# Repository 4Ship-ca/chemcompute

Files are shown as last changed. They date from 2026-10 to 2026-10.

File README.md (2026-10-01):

# chemcompute: WetStack-0

A home-lab chemical neuron: electrons in, chemistry decides, light out.

Charge pulses at platinum electrodes write acid or base into micro-chambers. A borax buffer sets each
chamber's firing threshold, a pH indicator shows its state, a camera and optical fiber read it, and reverse
charge resets it with no fluid replaced. The MVP ends with a two-layer chemical network computing XOR,
an ionic hydrogel diode, fiber readout and solar power, each proven by a pass/fail gate.

**Lab workspace (progress, gates, parts, photos, ask the lab manager):**
https://claude.ai/artifact/Spr4Hz1cUCdgWMjxmdhvYG

## Quick start

**Windows, one click:** double-click `start_wetstack.bat` in the repo folder. It finds Python 3.10+
(3.12 preferred), creates `.venv`, checks every dependency and installs or repairs what's missing,
runs the self-test after a fresh install, then starts the lab workspace and opens it in your browser.
Double-click it again while it's running and it just reopens the page. From a prompt it also runs any
other command in the venv: `start_wetstack.bat gate G0`, `start_wetstack.bat g1-linearity --sim`.
It serves on port 8765, or the next free port if another program already has it; set
`WETSTACK_PORT` to start the search somewhere else.

By hand (Windows or Linux):

```
python -m venv .venv
.venv\Scripts\activate          # Linux: source .venv/bin/activate
pip install -e .
python -m wetstack selftest     # every gate against the digital twin, about 30 s, must end PASSED
```

Then start every bench session with:

```
python -m wetstack serve --open
```

That opens the lab workspace in your browser and saves everything into the repo:
`progress/progress.json` (the master record), `PROGRESS.md` (checkboxes for GitHub) and
`photos/<step>/`. Saves are atomic, every save keeps a backup in `progress/backups/`, and if the
server stops, edits wait in the browser and save when it returns. The workspace's
Save and sync tab has a Commit button that commits and pushes the session.

Every experiment command takes `--sim` so you can rehearse it before using liquids:

```
python -m wetstack g1-linearity --sim
python -m wetstack gate G1 --sim
```

## Layout

| Path | What it is |
|---|---|
| `docs/LAB_MANUAL.md` | The full plan: path, architecture, materials, methods, every phase, step and gate |
| `bom/` | Parts lists with CAD estimates and AliExpress / Amazon search terms |
| `host/wetstack/` | Python package: experiments, camera pipeline, statistics, serial link, digital twin |
| `firmware/wetstack_ctl/` | ESP32 controller firmware (Arduino IDE) |
| `hardware/scad/`, `hardware/stl/` | Parametric OpenSCAD parts and ready STLs (plate frame, lid, fiber couplers) |
| `proofs/` | Gate proof files written by the experiment commands |
| `data/raw/` | Raw session data, never edited |
| `config/lab.json` | Your bench settings (created on first run) |
| `progress/progress.json` | Master progress record written by `python -m wetstack serve`; never edit by hand |
| `photos/<step>/` | Bench photos, resized to 1600 px |
| `tests/` | `test_progress.py` (storage) and `test_cli.py` (every manual command parses) must pass; `e2e_workspace.py` is the browser test (needs Playwright) |
| `tools/content.py` | Single source for the manual, BOM and workspace; rebuild with `python tools/build.py` |
| `start_wetstack.bat`, `tools/check_env.py` | Windows one-click launcher and the dependency / running-server check it uses |
| `web/` | Workspace page (offline copy works in any browser, saving to that browser only) |

## Status at handover

- Digital twin self-test: all ten gates pass.
- CAD: all parts render as manifold solids in OpenSCAD. Measure your plate and edit the parameters before printing the lid.
- Firmware: passes a syntax and type check against stub headers. It has not yet been compiled for a real ESP32; that is step P3.2.
- Real-bench results: none yet. That's your job.

## After each session

1. In the workspace, Sync tab: save `PROGRESS.md` and the progress JSON into the repo root.
2. `git add -A && git commit -m "session YYYYMMDD-x"`; tag passed gates (`git tag G1-pass`).
3. `git push --follow-tags`

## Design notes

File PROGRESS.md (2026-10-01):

# WetStack-0 progress

Starter file. Replace it with the PROGRESS.md exported from the workspace Sync tab after each session.

## P0 Bench, safety and calibration

- [ ] P0.1 Inventory against the BOM
- [ ] P0.2 Set up the bench
- [ ] P0.3 Install the software
- [ ] P0.4 Check the scale
- [ ] P0.5 Calibrate the 1000 uL pipette
- [ ] P0.6 Calibrate the 100 uL pipette
- [ ] P0.7 Read the safety rules and sign off

Gate G0 Bench certified: open

## P1 Eyes: the optical readout bench

- [ ] P1.1 Print the plate frame
- [ ] P1.2 Build the light station
- [ ] P1.3 Lock the camera
- [ ] P1.4 Mark the wells
- [ ] P1.5 Make the bromothymol blue stock (0.4 mg/mL)
- [ ] P1.6 Make 0.1 M sodium carbonate
- [ ] P1.7 Run the dilution series
- [ ] P1.8 Stability run

Gate G1 First light: open

## P2 First nonlinearity: manual XOR

- [ ] P2.1 Make the phenol red stock (0.2 mg/mL)
- [ ] P2.2 Make the input stocks
- [ ] P2.3 Balance the inputs
- [ ] P2.4 Make the XOR medium
- [ ] P2.5 Run the dual-indicator plates
- [ ] P2.6 Run the single-indicator control plate

Gate G2 First XOR: open

## P3 Electric write: the Faraday cell

- [ ] P3.1 Build the controller
- [ ] P3.2 Flash the firmware
- [ ] P3.3 Dry test the relays
- [ ] P3.4 Print and fit the lid
- [ ] P3.5 Make the electrodes
- [ ] P3.6 Verify the platinum
- [ ] P3.7 Make salt bridges
- [ ] P3.8 Calibrate coulomb counting
- [ ] P3.9 Standards and dose response

Gate G3 First electric write: open

## P4 The chemical neuron: threshold and reset

- [ ] P4.1 Make neuron media
- [ ] P4.2 Threshold sweep
- [ ] P4.3 Overnight reset run

Gate G4 First chemical neuron: open

## P5 Logic and the first stack

- [ ] P5.1 Find the AND and OR buffer levels
- [ ] P5.2 Truth tables
- [ ] P5.3 Wire the stack
- [ ] P5.4 Run 40 randomized trials
- [ ] P5.5 Cut-link control

Gate G5 First stack: open

## P6 Junctions: the ionic diode

- [ ] P6.1 Make Ag/AgCl electrodes
- [ ] P6.2 Cationic gel
- [ ] P6.3 Anionic gel
- [ ] P6.4 Cast three diode tubes and one control
- [ ] P6.5 I-V sweeps
- [ ] P6.6 Hysteresis on the scope

Gate G6 First diode: open

## P7 Fiber eyes

- [ ] P7.1 Print fiber parts
- [ ] P7.2 Cut and polish fiber
- [ ] P7.3 Assemble and read
- [ ] P7.4 Dose sweep with both readers

Gate G7 Fiber eyes: open

## P8 Sun power and energy per operation

- [ ] P8.1 Build the power board
- [ ] P8.2 Daylight session

Gate G8 Sun-powered: open

## P9 MVP integration

- [ ] P9.1 Full demo run
- [ ] P9.2 Generate the report
- [ ] P9.3 Debrief

Gate G9 MVP complete: open

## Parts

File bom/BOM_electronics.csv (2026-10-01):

id | name | qty | unit_cad_low | unit_cad_high | line_cad_low | line_cad_high | source | search_terms | first_needed | on_hand | notes
E01 | ESP32 DevKit V1 (classic ESP32-WROOM-32, 38-pin) | 2 | 6 | 12 | 12 | 24 | AliExpress | ESP32 DevKit V1 WROOM-32 38pin | P3 | no | Must be classic ESP32: S2, S3 and C3 have no DAC. Second board is a spare.
E02 | ADS1115 16-bit ADC module | 3 | 3 | 6 | 9 | 18 | AliExpress | ADS1115 module 16 bit | P3 | no | One shunt, one diode I-V, one spare. Set the second to address 0x49 (ADDR to VDD).
E03 | AS7341 11-channel spectral sensor module | 2 | 14 | 38 | 28 | 76 | AliExpress / Amazon (Adafruit) | AS7341 spectral sensor module | P7 | no | Adafruit version is easiest; Ali clones work with the same library.
E04 | 8-channel 5 V relay module, optocoupled, with JD-VCC jumper | 1 | 7 | 14 | 7 | 14 | AliExpress | 8 channel relay module 5V optocoupler | P3 | no | Low-level trigger type.
E05 | INA219 current/power module | 2 | 2 | 6 | 4 | 12 | AliExpress | INA219 module | P8 | no
E06 | DS18B20 waterproof temperature probe | 2 | 2 | 5 | 4 | 10 | AliExpress | DS18B20 waterproof probe | P3 | no
E07 | Logic-level MOSFET switch module (AO3400 or D4184) | 3 | 1 | 3 | 3 | 9 | AliExpress | D4184 MOSFET module | P3 | no | Not IRF520 modules: they do not switch fully at 3.3 V.
E08 | Coin vibration motors 10 mm, 3 V (10-pack) | 1 | 3 | 7 | 3 | 7 | AliExpress | coin vibration motor 1027 3V | P3 | no | Mixer.
E09 | MT3608 boost converter | 3 | 1 | 3 | 3 | 9 | AliExpress | MT3608 boost module | P8 | no
E10 | 9 V 1 A DC adapter + barrel jack breakout | 1 | 10 | 18 | 10 | 18 | Amazon | 9V 1A power adapter 5.5x2.1 | P3 | no
E11 | Inline fuse holder + 250 mA fast fuses | 1 | 5 | 10 | 5 | 10 | Amazon | inline fuse holder 5x20 250mA | P3 | no | Required.
E12 | 1% resistor kit (incl. 100, 470, 1k, 4.7k ohm) | 1 | 8 | 14 | 8 | 14 | AliExpress | 1% metal film resistor kit | P3 | yes | Verify on hand.
E13 | Perfboard, screw terminals, headers | 1 | 8 | 15 | 8 | 15 | AliExpress | perfboard screw terminal kit | P3 | no
E14 | Breadboard and jumper wires | 1 | 8 | 12 | 8 | 12 | AliExpress | 830 breadboard jumper kit | P3 | yes | Verify on hand.
E17 | TCA9548A I2C multiplexer | 1 | 2 | 4 | 2 | 4 | AliExpress | TCA9548A module | Stretch | no | For several AS7341 later.
O05 | 5 mm LED assortment (white, 450, 590, 630 nm) | 1 | 5 | 10 | 5 | 10 | AliExpress | 5mm LED assortment kit | P7 | no
O06 | 365 nm UV LEDs, 5 mm (20-pack) | 1 | 4 | 9 | 4 | 9 | AliExpress | 365nm UV LED 5mm | Stretch | no
S01 | Solar panel 6 V, 6 W | 1 | 18 | 35 | 18 | 35 | Amazon / AliExpress | 6V 6W solar panel | P8 | no
S02 | CN3791 MPPT single-cell solar charger module | 1 | 3 | 7 | 3 | 7 | AliExpress | CN3791 solar charger 6V | P8 | no | Get the 6 V input version.
S04 | 18650 holder with leads | 2 | 1 | 3 | 2 | 6 | AliExpress | 18650 battery holder | P8 | no

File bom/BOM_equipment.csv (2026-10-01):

id | name | qty | unit_cad_low | unit_cad_high | line_cad_low | line_cad_high | source | search_terms | first_needed | on_hand | notes
E15 | Multimeter with uA/mA ranges | 1 | 25 | 50 | 25 | 50 | Amazon | auto ranging multimeter microamp | P3 | yes | Verify on hand.
E16 | Oscilloscope | 1 | 0 | 0 | 0 | 0 | On hand |  | P6 | yes | On hand.
O01 | LED tracing light pad, A4, dimmable | 1 | 22 | 38 | 22 | 38 | Amazon | A4 LED light pad tracing dimmable | P1 | no | Even backlight for the plate.
O02 | USB webcam with manual exposure (Logitech C920/C922 class) | 1 | 50 | 110 | 50 | 110 | Amazon | Logitech C920 | P1 | no | Manual exposure and white balance are the requirement.
O03 | Overhead camera arm / desk mount | 1 | 20 | 38 | 20 | 38 | Amazon | overhead camera desk mount arm 1/4 | P1 | no
O07 | UV-blocking safety glasses | 1 | 10 | 22 | 10 | 22 | Amazon | UV protection safety glasses 365nm | Stretch | no
O08 | 18% gray / white reference card | 1 | 8 | 15 | 8 | 15 | Amazon | 18% gray card | P1 | yes | Verify on hand.
L01 | Adjustable micropipette 100-1000 uL | 1 | 25 | 60 | 25 | 60 | AliExpress / Amazon | adjustable micropipette 100-1000ul | P0 | no
L02 | Adjustable micropipette 10-100 uL | 1 | 25 | 60 | 25 | 60 | AliExpress / Amazon | adjustable micropipette 10-100ul | P0 | no
L05 | Digital scale 0.001 g / 50 g with calibration weight | 1 | 25 | 48 | 25 | 48 | Amazon | 0.001g digital scale 50g | P0 | no
L06 | Borosilicate beaker set 50-500 mL | 1 | 18 | 32 | 18 | 32 | Amazon | borosilicate beaker set | P0 | no
L07 | Graduated cylinders 10/50/100 mL | 1 | 14 | 26 | 14 | 26 | Amazon | graduated cylinder set | P0 | no
L13 | pH meter pen (0.01, ATC) + calibration powders | 1 | 20 | 42 | 20 | 42 | Amazon | pH meter 0.01 ATC calibration | P0 | no
L14 | Digital caliper 150 mm | 1 | 12 | 25 | 12 | 25 | AliExpress | digital caliper 150mm | P0 | no
L15 | Small magnetic hotplate stirrer + stir bars | 1 | 60 | 120 | 60 | 120 | Amazon | magnetic stirrer hot plate | P1 | no | Recommended. Microwave in short bursts is the fallback.
L16 | Silicone bench mat / spill tray | 1 | 10 | 22 | 10 | 22 | Amazon | silicone work mat large | P0 | no
L18 | Safety glasses (Z87.1) | 2 | 6 | 15 | 12 | 30 | Amazon | safety glasses Z87 | P0 | no
L23 | Fireproof LiPo charging bag | 1 | 10 | 18 | 10 | 18 | Amazon | lipo safe bag | P8 | no
L26 | 3D printers (resin + filament) | 1 | 0 | 0 | 0 | 0 | On hand |  | P1 | yes | On hand.

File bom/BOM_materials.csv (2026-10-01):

id | name | qty | unit_cad_low | unit_cad_high | line_cad_low | line_cad_high | source | search_terms | first_needed | on_hand | notes
O04 | PMMA end-glow optical fiber, 1.0 mm, 10 m | 1 | 8 | 16 | 8 | 16 | AliExpress | PMMA optical fiber 1mm end glow | P7 | no
O09 | Black foam board (2 sheets) for the light shroud | 1 | 6 | 14 | 6 | 14 | Local / Amazon | black foam board | P1 | no
L03 | Pipette tips 1000 uL (500) + 200 uL (1000) | 1 | 10 | 22 | 10 | 22 | AliExpress | pipette tips 1000ul 200ul | P0 | no
L04 | 24-well flat-bottom clear plates with lids (10-pack) | 1 | 18 | 38 | 18 | 38 | Amazon / AliExpress | 24 well plate flat bottom | P1 | no | Polystyrene, clear, flat bottom.
L08 | Amber glass dropper bottles 30 mL (12) | 1 | 12 | 20 | 12 | 20 | Amazon | amber glass dropper bottles 30ml | P1 | no
L09 | Storage bottles 250/500 mL (6) | 1 | 15 | 30 | 15 | 30 | Amazon | glass media bottle 500ml | P0 | no
L10 | Wash bottles 250/500 mL | 2 | 3 | 6 | 6 | 12 | AliExpress | lab wash bottle 500ml | P0 | no
L11 | Silicone tubing 2 mm ID x 3 mm OD, 5 m | 1 | 6 | 12 | 6 | 12 | AliExpress | silicone tube 2mm ID 3mm OD | P3 | no | Salt bridges and diode tubes.
L12 | 10 mL luer syringes (10) + blunt needles 14-18 G | 1 | 10 | 18 | 10 | 18 | Amazon | 10ml syringe blunt tip needle | P3 | no
L17 | Nitrile gloves (100) | 1 | 10 | 18 | 10 | 18 | Amazon / local | nitrile gloves | P0 | no
L19 | Lab notebook, labels, waterproof markers | 1 | 10 | 20 | 10 | 20 | Local |  | P0 | no
L20 | Transfer pipettes 3 mL (100) | 1 | 5 | 10 | 5 | 10 | AliExpress | plastic transfer pipette 3ml | P0 | no
L22 | Weighing boats, spatulas, small funnels | 1 | 8 | 16 | 8 | 16 | AliExpress | lab spatula weighing boat set | P0 | no
L27 | PETG filament / clear resin | 1 | 0 | 0 | 0 | 0 | On hand |  | P1 | yes | On hand. PETG for wet parts.
X01 | Platinum wire 0.3 mm x 10 cm, 99.95% | 1 | 15 | 45 | 15 | 45 | AliExpress | platinum wire 0.3mm 99.95 | P3 | no | Verify with step P3.6.
X02 | Graphite rods 2 mm (pure, art leads) | 1 | 6 | 12 | 6 | 12 | Amazon / AliExpress | 2mm graphite lead refill pure | P3 | no | Counter electrode; Pt fallback.
X03 | Silver wire 999, 0.5 mm x 1 m | 1 | 15 | 40 | 15 | 40 | AliExpress | 999 silver wire 0.5mm | P6 | no | For Ag/AgCl.
C01 | Distilled water, 4 L | 4 | 2 | 4 | 8 | 16 | Grocery |  | P0 | no
C02 | Bromothymol blue powder (5-10 g) | 1 | 12 | 28 | 12 | 28 | Amazon | bromothymol blue powder | P1 | no | Backup: aquarium pH test solution (bromothymol blue).
C03 | Phenol red powder (5 g) or 0.02% solution | 1 | 12 | 28 | 12 | 28 | Amazon | phenol red indicator | P2 | no | Pool test phenol red works if concentration is listed.
C04 | Universal indicator solution 100 mL | 1 | 12 | 20 | 12 | 20 | Amazon | universal indicator solution | P2 | no | Backup for XOR.
C05 | Sodium sulfate anhydrous 500 g | 1 | 12 | 22 | 12 | 22 | Amazon | sodium sulfate anhydrous | P1 | no
C06 | Sodium bisulfate (pool pH Down, 93%+) 1 kg | 1 | 10 | 16 | 10 | 16 | Amazon / pool store | sodium bisulfate pH down | P2 | no
C07 | Sodium carbonate (washing soda / pH Up) 1 kg | 1 | 6 | 12 | 6 | 12 | Grocery / Amazon | washing soda sodium carbonate | P1 | no
C09 | Disodium phosphate, food grade, 250-500 g | 1 | 12 | 22 | 12 | 22 | Amazon | disodium phosphate food grade | P2 | no | Note the hydrate form on the label.
C22 | Borax (sodium tetraborate decahydrate), laundry grade OK | 1 | 6 | 14 | 6 | 14 | Grocery / Amazon | 20 Mule Team Borax | P4 | no | Neuron buffer. Gloves; keep from kids and pets.
C10 | Monosodium phosphate, food grade, 250-500 g | 1 | 12 | 22 | 12 | 22 | Amazon | monosodium phosphate food grade | P2 | no
C11 | Agar-agar powder 100 g | 1 | 10 | 16 | 10 | 16 | Grocery / Amazon | agar agar powder | P3 | no | Salt bridges.
C12 | Agarose LE, molecular biology grade, 25 g | 1 | 35 | 70 | 35 | 70 | Amazon | agarose powder molecular biology | P6 | no | Low charge; agar is not a substitute for the diode.
C13 | Chitosan powder, medium MW, 100 g | 1 | 20 | 38 | 20 | 38 | Amazon | chitosan powder | P6 | no | Cationic side of the diode.
C14 | Sodium alginate, food grade, 100 g | 1 | 10 | 18 | 10 | 18 | Amazon | sodium alginate | P6 | no | Anionic side.
C15 | Sodium polyacrylate (SAP) 250 g | 1 | 10 | 16 | 10 | 16 | Amazon | sodium polyacrylate powder | P6 | no | Backup anionic side.
C21 | Non-iodized table salt | 1 | 2 | 4 | 2 | 4 | Grocery |  | P6 | no | Diode test wells only.
C16 | White vinegar 5% | 1 | 3 | 5 | 3 | 5 | Grocery |  | P6 | no
C17 | Isopropyl alcohol 99%, 500 mL | 1 | 8 | 15 | 8 | 15 | Pharmacy / Amazon | isopropyl alcohol 99% | P1 | no
C18 | Household bleach, unscented | 1 | 3 | 6 | 3 | 6 | Grocery |  | P6 | no | Own labeled jar. Never near acids.
C19 | Calcium chloride food grade 250 g | 1 | 8 | 14 | 8 | 14 | Amazon | calcium chloride food grade | Stretch | no
C20 | Photochromic pigment powder 10 g | 1 | 6 | 12 | 6 | 12 | AliExpress | photochromic pigment powder UV | Stretch | no
S03 | Protected 18650 Li-ion cell, reputable brand | 2 | 12 | 25 | 24 | 50 | Local battery shop / Amazon | protected 18650 battery | P8 | no | Do not buy cells on AliExpress.

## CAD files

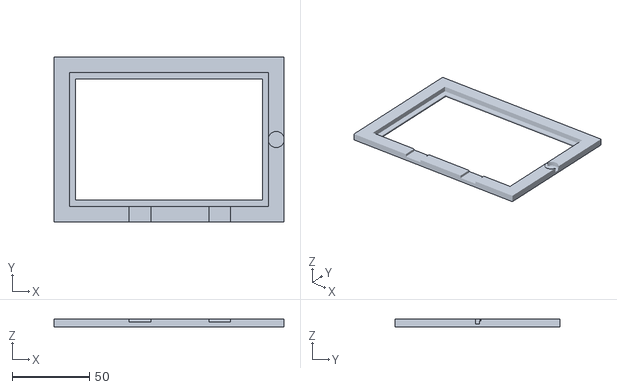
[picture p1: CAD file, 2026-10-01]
hardware/stl/plate_frame.stl
149.0 x 106.7 x 5.00

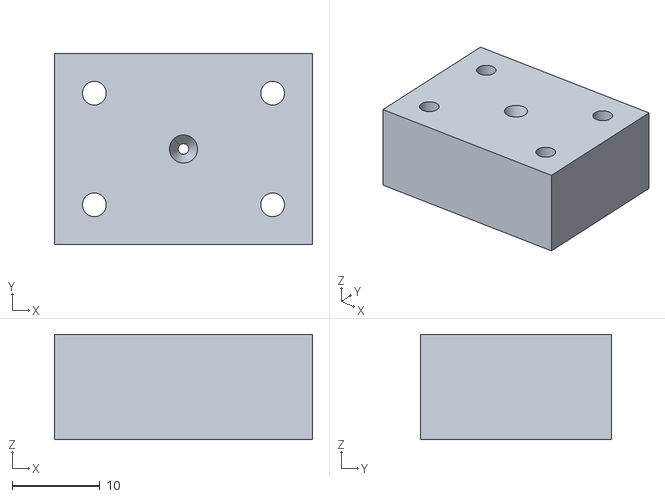
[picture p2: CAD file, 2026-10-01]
hardware/stl/fiber_sensor_cap.stl
29.4 x 21.8 x 12.0

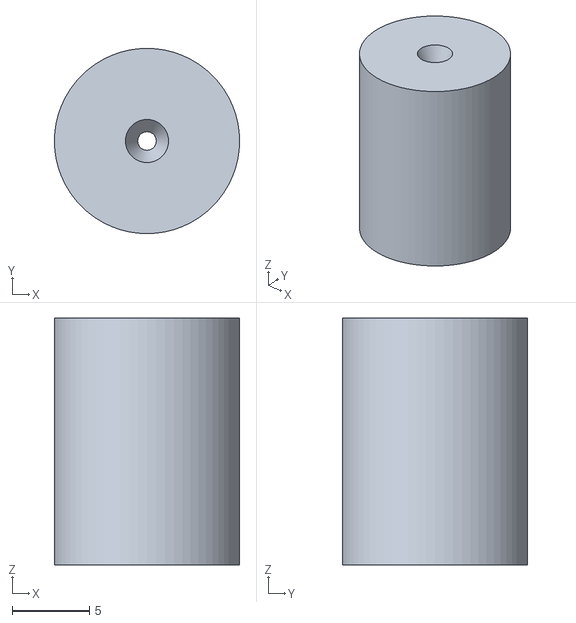
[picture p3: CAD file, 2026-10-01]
hardware/stl/fiber_led_coupler.stl
12.0 x 12.0 x 16.0

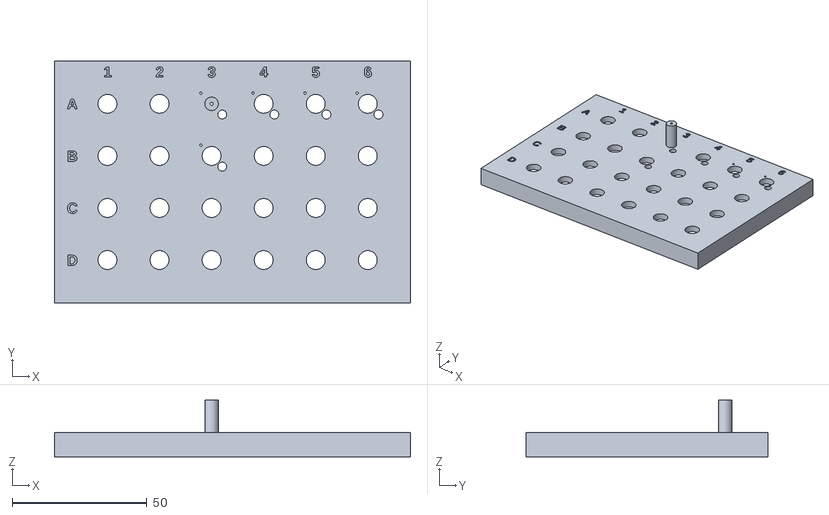
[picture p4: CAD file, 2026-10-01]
hardware/stl/plate_lid_fiber_A3.stl
132.0 x 89.7 x 21.0

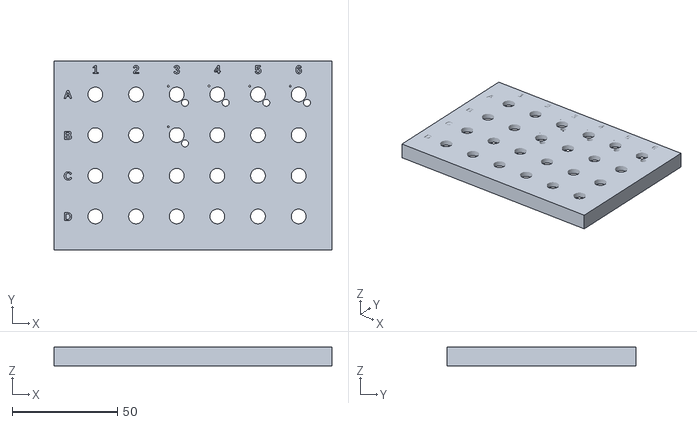
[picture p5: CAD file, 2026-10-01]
hardware/stl/plate_lid.stl
132.0 x 89.7 x 9.00

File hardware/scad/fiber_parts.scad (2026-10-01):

// WetStack-0 fiber parts (Phase 7). part = "led" prints the LED-to-fiber coupler,
// part = "cap" prints the light-tight cap that holds a fiber over the AS7341 sensor.
// Clone AS7341 boards vary: measure yours and edit the board block.

part = "led";            // "led" or "cap"
fiber_d = 1.2;           // bore for 1.0 mm PMMA fiber
$fn = 64;

// LED coupler: 5 mm LED pushed in from one end, fiber from the other, tip to tip
led_d = 5.1;  led_len = 8.6;  flange_d = 6.0;  flange_h = 1.2;  body_d = 12;  body_h = 16;

// AS7341 board (Adafruit defaults)
board_x = 25.4;  board_y = 17.8;  board_t = 1.6;
sensor_x = 12.7; sensor_y = 8.9;          // sensor centre from the board's lower-left corner
hole_inset = 2.54;  hole_d = 2.7;
cap_h = 12;  skirt_h = 4;  wall = 2;

module led_coupler() {
  difference() {
    cylinder(d = body_d, h = body_h);
    translate([0, 0, -0.01]) cylinder(d = flange_d, h = flange_h);
    translate([0, 0, -0.01]) cylinder(d = led_d, h = led_len);
    translate([0, 0, led_len - 0.5]) cylinder(d = fiber_d, h = body_h);
    translate([0, 0, body_h - 2]) cylinder(d1 = fiber_d, d2 = fiber_d + 1.6, h = 2.01); // lead-in
  }
}

module sensor_cap() {
  difference() {
    translate([-wall, -wall, 0]) cube([board_x + 2*wall, board_y + 2*wall, cap_h]);
    translate([0, 0, -0.01]) cube([board_x, board_y, skirt_h]);                       // board pocket
    translate([sensor_x, sensor_y, -1]) cylinder(d = fiber_d, h = cap_h + 2);          // fiber bore
    translate([sensor_x, sensor_y, cap_h - 3]) cylinder(d1 = fiber_d, d2 = fiber_d + 2, h = 3.01);
    translate([sensor_x, sensor_y, skirt_h - 0.01]) cylinder(d = 3.0, h = 1.5);        // clear the sensor package
    for (x = [hole_inset, board_x - hole_inset], y = [hole_inset, board_y - hole_inset])
      translate([x, y, -1]) cylinder(d = hole_d, h = cap_h + 2);
  }
}

if (part == "led") led_coupler(); else sensor_cap();

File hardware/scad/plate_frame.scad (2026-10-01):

// WetStack-0 plate locator frame: holds a 24-well plate in the same spot on the light pad
// every session, with a pocket for the coin vibration motor (the mixer).
// Measure YOUR plate with calipers and edit the first block. Print in PETG, 0.2 mm layers.

plate_len = 127.76;   // outer length of the plate footprint (mm)
plate_wid = 85.48;    // outer width
clear     = 0.6;      // clearance per side
border    = 10;       // frame border width
height    = 5;        // frame height
base      = 1.2;      // floor lip thickness under the plate edge
lip       = 4;        // how far the lip reaches under the plate
motor_d   = 10.4;     // coin motor 1027: 10 mm diameter
motor_h   = 3.2;
$fn = 64;

L = plate_len + 2*clear;
W = plate_wid + 2*clear;

difference() {
  translate([-border, -border, 0]) cube([L + 2*border, W + 2*border, height]);
  translate([0, 0, base]) cube([L, W, height]);                       // plate pocket
  translate([lip, lip, -1]) cube([L - 2*lip, W - 2*lip, height + 2]); // light window
  translate([L + border/2, W/2, height - motor_h]) cylinder(d = motor_d, h = motor_h + 1); // motor pocket
  translate([L - 1, W/2 - 1.5, height - motor_h]) cube([border/2 + 1, 3, motor_h + 1]);   // motor touches plate wall
  translate([L + border/2 - 1, W/2, height - 1.2]) cube([border, 2.2, 2]);                // wire channel
  for (x = [L*0.3, L*0.7]) translate([x, -border - 1, height - 2]) cube([14, border + 2, 3]); // finger notches
}

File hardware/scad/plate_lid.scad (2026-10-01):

// WetStack-0 plate lid: a view window over every well, plus electrode and salt-bridge holes
// over the electrode wells, and optional fiber bosses (Phase 7).
// Measure YOUR plate and edit the first block. Print in PETG; test-fit before adding electrodes.

plate_len = 127.76;  plate_wid = 85.48;  // plate footprint
a1_x      = 17.53;                       // A1 centre from the plate's left edge (column axis)
a1_y      = 13.77;                       // A1 centre from the plate's top edge (row axis)
pitch     = 19.30;                       // well centre spacing
well_d    = 15.6;                        // well inner diameter
clear     = 0.5;  wall = 1.6;  top = 3.0;  skirt = 6;

window_d   = 7.0;   // camera window over every well
electrode_d = 0.9;  // 0.3 mm Pt wire through a 0.9 mm hole, sealed with a dab of epoxy on top
bridge_d   = 3.3;   // 3 mm OD silicone tube
fiber_d    = 1.2;   // 1.0 mm PMMA fiber
port_r     = 5.6;   // radius at which electrode and bridge holes sit

// Electrode wells as [row, column], zero based: A3 A4 A5 A6 B3 (W1..W5)
electrode_wells = [[0,2],[0,3],[0,4],[0,5],[1,2]];
// Wells that get a fiber boss instead of a window (Phase 7), e.g. [[0,2]]
fiber_wells = [];
$fn = 48;

L = plate_len + 2*clear;  W = plate_wid + 2*clear;
function centre(r, c) = [wall + clear + a1_x + c*pitch, wall + clear + (plate_wid - a1_y) - r*pitch];
function has(list, rc) = len([for (x = list) if (x[0] == rc[0] && x[1] == rc[1]) 1]) > 0;

module body() {
  difference() {
    cube([L + 2*wall, W + 2*wall, top + skirt]);
    translate([wall, wall, -1]) cube([L, W, skirt + 1]);
  }
}

difference() {
  union() {
    body();
    for (rc = fiber_wells) translate([each centre(rc[0], rc[1]), skirt]) cylinder(d = 5, h = top + 12);
  }
  for (r = [0:3], c = [0:5]) {
    p = centre(r, c);
    if (!has(fiber_wells, [r, c])) translate([p[0], p[1], -1]) cylinder(d = window_d, h = top + skirt + 2);
    else translate([p[0], p[1], -1]) cylinder(d = fiber_d, h = top + skirt + 20);
    if (has(electrode_wells, [r, c])) {
      translate([p[0] + port_r*cos(135), p[1] + port_r*sin(135), -1]) cylinder(d = electrode_d, h = top + skirt + 2);
      translate([p[0] + port_r*cos(315), p[1] + port_r*sin(315), -1]) cylinder(d = bridge_d, h = top + skirt + 2);
    }
  }
  // row and column labels engraved on the top surface
  for (r = [0:3]) translate([wall + 3, centre(r, 0)[1] - 2, top + skirt - 0.6])
    linear_extrude(1) text(["A","B","C","D"][r], size = 4, font = "Liberation Sans:style=Bold");
  for (c = [0:5]) translate([centre(0, c)[0] - 1.5, W + 2*wall - 6, top + skirt - 0.6])
    linear_extrude(1) text(str(c + 1), size = 4, font = "Liberation Sans:style=Bold");
}

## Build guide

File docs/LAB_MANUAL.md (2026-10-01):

# WetStack-0 lab manual

_A home-lab chemical neuron: electrons in, chemistry decides, light out._

Generated from tools/content.py by tools/build.py. The web workspace (web/wetstack_lab.html) shows the same content with progress tracking.

## MVP definition

- Electrical inputs (charge pulses) write acid or base into at least 3 micro-chambers.
- The chemistry, not software, supplies every nonlinearity (buffer threshold + indicator speciation).
- Chambers are read optically by camera and by optical fiber into a spectral sensor.
- Chambers reset electrically for 100+ cycles with no fluid replaced.
- A two-layer chemical network computes XOR at 95% or better over 40+ randomized trials, with electronics allowed only to scale signals between layers (the linear-relay rule).
- An ionic diode junction is built and characterized (rectification ratio 2 or better).
- The electronics run from solar, and joules per chemical operation are measured.

## Working principles

- **Linear-relay rule.** Between chemical layers, electronics may only multiply a measured signal by a fixed gain. No thresholds, no if-statements, no clipping in software. Every decision must happen in a well.
- **Absorbance, not brightness.** Readout features are absorbances (log of light ratio), so Beer-Lambert's exponential cannot sneak in a nonlinearity. Any separability we claim belongs to the chemistry.
- **Every claim has a control.** Each positive result is paired with a run that should fail (single indicator, raw inputs, shuffled labels, undoped gel). If the control passes too, the claim does not stand.
- **Simulate first, then wet.** Every experiment runs against the digital twin with --sim before a drop of liquid is used. The sim is also the reference you compare real data against.
- **Gates are pass/fail.** You do not start a phase until the previous gate passes or I sign off on a documented exception.

## Roles

- **Lab manager (Claude):** Sets the plan, the gates and the safety rules; reviews data and photos; decides on exceptions.
- **Technician / instructor (Claude):** Explains each step and why; troubleshoots failed gates with you.
- **Lab partner (you):** Builds, runs, measures, photographs and records. You stop and ask when anything surprises you.

## (a) Path to MVP

Which physical route gets a home lab to a working, honest chemical-compute MVP fastest and safest?

| Option | Safety at home (x3) | Cost (x2) | Speed per op (x1) | Reversible (low consumables) (x3) | Easy to observe (x2) | Fits the long-term vision (x2) | Weighted |
|---|---|---|---|---|---|---|---|
| Electro-chemical pH neuron (chosen) | 5 | 5 | 3 | 5 | 5 | 4 | 61 |
| DNA strand displacement | 5 | 1 | 1 | 2 | 3 | 4 | 38 |
| Belousov-Zhabotinsky oscillators | 2 | 4 | 4 | 3 | 5 | 4 | 45 |
| Lipid droplet synapses | 4 | 3 | 4 | 3 | 2 | 5 | 45 |
| Living neurons / organoids | 1 | 1 | 4 | 2 | 2 | 5 | 29 |
| Pure reservoir in a stirred vat | 5 | 5 | 2 | 2 | 4 | 2 | 45 |

Scores are 1 (poor) to 5 (best).

- **Electro-chemical pH neuron (chosen):** Charge pulses make acid or base at a platinum electrode; a buffer sets the firing threshold; an indicator shows the state; reverse charge resets it. Cheap, safe, reversible, visible.
- **DNA strand displacement:** Elegant and programmable, but custom DNA strands cost hundreds per design and reactions take hours.
- **Belousov-Zhabotinsky oscillators:** Real excitable medium, but uses strong acid and bromate. Not a first home build.
- **Lipid droplet synapses:** Closest to biology, but needs picoamp electrophysiology and fragile membranes.
- **Living neurons / organoids:** Needs a cell-culture lab. Out of scope for a home bench.
- **Pure reservoir in a stirred vat:** Works (Huck lab, Nature 2024) but has no spatial structure to grow into stacked layers.

**Decision:** Electro-chemical pH neuron, read optically, with an ionic-diode junction as the first inter-chamber element.

- It is the smallest system that has all five parts of your vision: input, threshold, state, readout, reset.
- Faraday's law makes the input exact: charge in coulombs maps to moles of acid, so we can reason quantitatively.
- Reverse charge undoes a write, which attacks the consumables problem from day one.
- Everything upgrades in place: the salt bridge becomes a diode, the camera becomes a fiber, the wall plug becomes the sun.

## (b) Architecture

A PC orchestrates an ESP32 controller. The controller writes charge into chosen wells of a 24-well plate through platinum electrodes; every well connects to one shared counter-electrode reservoir through its own salt bridge. Each well holds an electrolyte, a phosphate buffer and a pH indicator. A camera above a light pad reads every well at once; later, fibers read single wells into a spectral sensor. Analysis and the trained readout run in Python on the PC.

| Layer | Hardware | Role |
|---|---|---|
| L0 Host | PC (Linux or Windows), Python 3.10+ | Runs experiments, camera capture, digital twin, analysis, proofs; git holds everything. |
| L1 Controller | ESP32 DevKit V1 (classic WROOM-32) | Relays, coulomb counting (ADS1115), spectral reads (AS7341), DAC sweeps for diode I-V, temperature, power. |
| L2 Electro-fluidic | 24-well plate, printed lid, Pt working electrodes, agar salt bridges, counter reservoir | Delivers charge into a well and closes the circuit through ions, not wires. |
| L3 Chemistry | 50 mM sodium sulfate + borax (neurons) or phosphate (calibration) + bromothymol blue (+ phenol red) | Buffer = threshold, indicator = output, electrode charge = weighted input. |
| L4 Optics | LED light pad, webcam with locked exposure, PMMA fiber + AS7341 | Absorbance per well per color channel; fiber reaches wells a camera cannot see. |
| L5 Power | 9 V adapter, then 6 V solar panel + 18650 + boost converters | Energy per operation measured with an INA219. |

Signal flow: Input bits -> Charge doses (mC) -> H+ or OH- (Faraday's law) -> Buffer absorbs until capacity runs out -> Indicator flips color past the threshold -> Camera / fiber absorbance -> Linear readout or linear relay to the next layer

### Pin map

| Pin | Function | Connects to |
|---|---|---|
| GPIO21 / GPIO22 | I2C SDA / SCL | ADS1115 #1 (0x48, shunt), ADS1115 #2 (0x49, diode I-V), AS7341 (0x39), INA219 (0x40) |
| GPIO25 / GPIO26 | DAC1 / DAC2 | Diode cell drive, differential: V = DAC1 - DAC2 |
| GPIO16 | Relay CH1 | Master enable (connects +9 V through the 470 ohm limit resistor) |
| GPIO17 | Relay CH2 + CH3 (both IN pins) | Polarity pair. Off = ACID write (well electrode is anode). On = BASE write. |
| GPIO18, 19, 23, 32, 33 | Relay CH4..CH8 | Well select W1..W5 (only one on at a time, enforced in firmware) |
| GPIO13 | MOSFET module #1 | Vibration mixer (coin motor on the plate frame) |
| GPIO14 | MOSFET module #2 | External fiber LED for differential spectral reads |
| GPIO4 | OneWire + 4.7 kohm pull-up to 3.3 V | DS18B20 temperature probe in the counter reservoir |
| GPIO2 | On-board LED | Busy indicator |

### Wiring notes

- Relay board: remove the JD-VCC jumper. Feed VCC (optocoupler side) from 3.3 V and JD-VCC (coils) from 5 V. Otherwise a 3.3 V HIGH may not turn a channel fully off.
- Polarity pair from two SPDT relays: Relay A COM to the working bus, A-NC to the supply node S, A-NO to the return node R. Relay B COM to the counter electrode, B-NC to R, B-NO to S.
- Each well relay: COM to the working bus, NO to that well's platinum electrode.
- Return node R goes through the 100 ohm shunt to ground. ADS1115 #1 reads A0 (top of shunt) minus A1 (ground). The shunt never leaves ground potential, so the ADC is always safe.
- Put a 250 mA fuse right after the 9 V adapter. Liquids and power share a bench; the fuse is not optional.
- Diode cell: DAC1 to a 1 kohm sense resistor to electrode A; electrode B to DAC2. ADS1115 #2 reads A0-A1 across the resistor and A2-A3 across the cell.

### Design decisions

- **24-well plate before custom chambers.** Standard footprint, clear bottoms, cheap. Custom resin chambers come after the chemistry works.
- **Platinum working electrodes.** Graphite flakes and steel dissolves when used as an anode; both would contaminate the optics. Graphite is fine for the counter electrode, which sits in a separate reservoir.
- **Sodium sulfate electrolyte, never chloride.** Chloride at an anode makes chlorine. Sulfate is inert and safe.
- **Shared counter reservoir via salt bridges.** Without separating the counter electrode, the acid and base you make cancel inside the same well.
- **Relays, not transistors, for routing.** Slow is fine (doses take seconds); relays isolate completely and forgive wiring mistakes.
- **Bromothymol blue for neurons, plus phenol red for XOR.** One indicator gives a clean threshold. Two indicators with different pKa give a curved color path, which a linear readout needs for XOR.
- **Borax buffer for neurons, phosphate for calibration.** Borax buffers near pH 9.2, well above the indicator's color change at 7.1, so the well stays blue until the buffer is used up and then flips sharply. Phosphate (pKa 7.2) sits on the color change and smooths it, which is what we want for calibration and not for thresholds.
- **Webcam first, fiber second.** The camera reads all wells at once to develop the chemistry; fiber is the upgrade for buried layers.

## (c) Materials

Full lists with search terms: bom/BOM_electronics.csv, bom/BOM_equipment.csv, bom/BOM_materials.csv.

| Group | Estimate (CAD) |
|---|---|
| consumable | 134-262 |
| electronics | 130-293 |
| equipment | 333-691 |
| material | 267-545 |
| **Total, items not on hand** | **864-1791** |

Spend by phase (order just ahead of each phase):

| Phase | Estimate (CAD) |
|---|---|
| P0 | 233-489 |
| P1 | 226-455 |
| P2 | 58-108 |
| P3 | 108-228 |
| P4 | 6-14 |
| P6 | 98-197 |
| P7 | 41-102 |
| P8 | 64-137 |
| Stretch | 30-61 |

Prices are late-2026 estimates from typical AliExpress and Amazon.ca listings; verify at purchase.

### Recipes

- **100 mM phosphate, pH 7.6 (100 mL).** 7.1 mmol disodium phosphate + 2.9 mmol monosodium phosphate, water to 100 mL. Masses by the form on your label: Na2HPO4 anhydrous 1.01 g, dihydrate 1.26 g, heptahydrate 1.90 g, dodecahydrate 2.54 g; NaH2PO4 anhydrous 0.35 g, monohydrate 0.40 g, dihydrate 0.45 g. Check with the pH meter; nudge with drops of carbonate or bisulfate.
- **Cell medium (per 100 mL).** 0.71 g sodium sulfate (50 mM), phosphate stock for the buffer level you need (1 mL per 1 mM), 6.25 mL bromothymol blue stock (40 uM), water to 100 mL. Used for calibration (P3).
- **100 mM borate stock (100 mL).** 0.953 g borax (sodium tetraborate decahydrate) in water to 100 mL. It buffers itself at pH 9.2; no adjustment needed. Gloves; do not ingest.
- **Neuron medium (per 100 mL).** 0.71 g sodium sulfate, borate stock for the level you need (1 mL per 1 mM total borate), 6.25 mL bromothymol blue stock, water to 100 mL. Deep blue at the start.
- **Bromothymol blue stock 0.4 mg/mL.** 40 mg in 5 mL isopropyl alcohol, + 90 mL water, carbonate drops until blue-green, to 100 mL.
- **Phenol red stock 0.2 mg/mL.** 20 mg in 5 mL isopropyl alcohol, + 90 mL water, carbonate drops until red, to 100 mL.
- **Salt bridge gel.** 2 g agar in 100 mL of 0.25 M sodium sulfate (3.55 g anhydrous). Heat until clear.
- **Counter reservoir.** 100 mL of 0.25 M sodium sulfate in a beaker, graphite rod, temperature probe.
- **Reference wells.** A1: cell medium + 50 uL of 200 mM bisulfate (pH about 4). A2: cell medium + 50 uL of 0.1 M carbonate (pH about 9.5).

## (d) Methods

- **Session IDs.** Every bench session gets an ID like 20261005-a. Raw files go to data/raw/<session>/ and are never edited.
- **Randomized layouts.** The scripts assign which well gets which condition. You follow the printed map. This stops position effects from faking a result.
- **Reference wells.** Wells A1 (acid reference, pH 4) and A2 (base reference, pH 9.5) sit on every plate. Each read is normalized to them, which cancels lamp and camera drift.
- **Replicates.** Minimum three repeats for any calibration point; 48 wells for classification claims; 40 trials for the stack.
- **Statistics.** Accuracy with a 95% Wilson interval; 1000-shuffle permutation test for classification; logistic fits for thresholds; R-squared for calibrations.
- **Controls.** Raw-input linear baseline, single-indicator control, shuffled labels, undoped gel, reverse polarity. Listed per gate.
- **Temperature.** Log reservoir temperature on every run. Indicator pKa shifts with temperature; a 5 C change is visible.
- **Version control.** Commit after every session (the workspace's Commit button does it). Tag each passed gate (git tag G3-pass). Proof JSON files live in proofs/.
- **Progress records.** progress/progress.json in the repo is the master record, written by python -m wetstack serve. Every save is atomic and keeps a backup in progress/backups/. If two writers collide, items merge by timestamp; nothing is dropped. PROGRESS.md is regenerated from it on every save.
- **Photos.** Photograph every build step and every gate result, and upload it to the step in the workspace.
- **When a gate fails.** Stop. Record the numbers. Work the troubleshooting list for that gate. Ask in the workspace with your data attached before changing two things at once.

### Safety

- **Eyes.** Safety glasses on whenever liquids or powders are open. UV glasses for any 365 nm LED work.
- **Hands.** Nitrile gloves for indicators, phosphate, bisulfate, chitosan and bleach.
- **Never mix bleach with acid.** Bleach is used only to coat silver wire, in its own labeled jar, rinsed off before the wire touches anything else. Bleach plus acid (including vinegar, citric acid, sodium bisulfate) releases chlorine gas.
- **No chloride in electrolysis cells.** Sodium sulfate only in the platinum cells. Chloride at a platinum anode makes chlorine. The one exception is the diode test (P6), where Ag/AgCl electrodes need dilute salt and the silver reacts first.
- **Low voltage only.** 12 V DC maximum on the bench, fused at 250 mA. No mains-powered device sits where a spill can reach it.
- **Electrolysis gas.** Currents are a few milliamps, so hydrogen and oxygen volumes are tiny. Keep the area ventilated and never seal a running cell airtight.
- **Hot agar and agarose.** Microwave in 15 s bursts with a loose cover; superheated gel can boil over. Use heat-resistant gloves.
- **Lithium cells.** Protected 18650 cells from a reputable seller only. Charge in a fireproof bag, never unattended.
- **Kitchen separation.** Dedicated labware only. Nothing from the lab returns to food use. Label every bottle with contents, concentration and date.
- **Waste.** Neutralize to pH 6-8 and flush small indicator and salt solutions with plenty of water, if your municipal rules allow. Silver and gel waste go to solid waste in a sealed bag.
- **Kids and pets.** The bench is off-limits when chemicals are out. Store stocks closed and high.

Every experiment command accepts --sim to run against the digital twin in host/wetstack/sim.py: phosphate buffer equilibria, indicator speciation, Faraday dosing with efficiency, camera absorbance noise, a gel-diode model and a power model. Run it before every wet session so you know what a good result looks like.

## Phases, gates and steps

### P0 Bench, safety and calibration (Week 1)

**Goal.** A safe, calibrated, documented bench and a working software environment.

**Why.** Every later number depends on pipette volumes, a clean bench and the digital twin running. Ten careful hours here save weeks.

- [ ] **P0.1 Inventory against the BOM.** Open the BOM tab. Mark each item Have, Ordered or Need. Photograph your on-hand electronics and printers. (photo)
- [ ] **P0.2 Set up the bench.** Choose a surface away from food prep. Lay the silicone mat or spill tray. Place the waste jar, wash bottle of distilled water, gloves and glasses within reach. Photograph the bench. (photo)
- [ ] **P0.3 Install the software.** Unzip the repo (or clone your GitHub copy). Windows, one click: double-click start_wetstack.bat in the repo folder; it creates .venv, installs and checks the dependencies, runs the self-test below once and opens the workspace, and it is how you start every session after that. By hand instead, in a terminal at the repo root: python -m venv .venv, activate it (Windows: .venv\Scripts\activate, Linux: source .venv/bin/activate), then pip install -e . and run the full digital twin. It takes about a minute and must end with Self-test PASSED. From then on, start every session with python -m wetstack serve --open: the workspace opens in your browser and saves into progress/progress.json in the repo. `python -m wetstack selftest --sim`
- [ ] **P0.4 Check the scale.** Weigh the calibration weight that came with the scale three times. All three readings should be within 0.005 g of the stated value. Tare between readings.
- [ ] **P0.5 Calibrate the 1000 uL pipette.** Set 1000 uL. Tare a small beaker. Dispense distilled water ten times, recording the scale after each (1 mg equals 1 uL at room temperature). Enter the ten cumulative readings when the script asks. `python -m wetstack g0-pipette --volume 1000`
- [ ] **P0.6 Calibrate the 100 uL pipette.** Same method at 100 uL, ten dispenses. `python -m wetstack g0-pipette --volume 100`
- [ ] **P0.7 Read the safety rules and sign off.** Read the Safety tab top to bottom. Tick this step only when every rule is set up physically (bleach jar labeled, fuse on hand, glasses at the bench).

**Gate G0: Bench certified** (`python -m wetstack gate G0`)

| Criterion | Target |
|---|---|
| 1000 uL mean error | <= 3 % |
| 1000 uL repeatability (CV) | <= 2 % |
| 100 uL mean error | <= 3 % |
| 100 uL repeatability (CV) | <= 2 % |
| Digital twin self-test passes | == 1  |
| Safety rules set up and signed | == 1  |

If it fails:

- Pipette error high: pre-wet the tip twice, dispense against the beaker wall, hold the pipette vertical, check the tip seats fully.
- Error still high but CV low: the pipette is consistently off; use the measured factor as a correction in config/lab.json.
- Self-test fails: run python -m wetstack selftest --sim --verbose and paste the output into Ask.

Achievement: **Bench certified**

### P1 Eyes: the optical readout bench (Weeks 1-2)

**Goal.** Read the color of every well reliably as absorbance.

**Why.** If the readout drifts or saturates, no chemistry result can be trusted. We prove the eyes before we trust what they see.

- **H1.** With locked exposure and reference-well normalization, red-channel absorbance of a bromothymol blue dilution series in base is linear in concentration (Beer-Lambert), and repeated reads vary by under 2%. _Pass:_ R-squared >= 0.98; repeat CV <= 2%; 10-minute drift <= 1%. _Control:_ A water-only well reads under 0.05 absorbance (the plastic and meniscus).

- [ ] **P1.1 Print the plate frame.** Measure your 24-well plate with calipers (outer length and width, well pitch, A1 center offset). Enter them at the top of hardware/scad/plate_frame.scad and plate_lid.scad. Print the frame in PETG, 0.2 mm layers. (photo)
- [ ] **P1.2 Build the light station.** Light pad flat on the bench, frame taped onto it, camera on the overhead arm about 30 cm above, lens centered over the plate. Surround with black foam board so room light cannot reach the plate. Photograph it. (photo)
- [ ] **P1.3 Lock the camera.** Run the camera tool. It tries to turn off auto exposure, auto white balance and autofocus. If your camera ignores it, set those manually in the camera app (Windows: Logitech G HUB or the Camera app's pro mode; Linux: v4l2-ctl or guvcview), then rerun. `python -m wetstack camera --lock --preview`
- [ ] **P1.4 Mark the wells.** Put the empty plate in the frame. Click the center of each well A1 to D6 in order, then click a bare spot of the light pad as the white reference. ROIs save to config/rois.json. `python -m wetstack calibrate-rois`
- [ ] **P1.5 Make the bromothymol blue stock (0.4 mg/mL).** Gloves and glasses. Weigh 40 mg bromothymol blue. Dissolve in 5 mL isopropyl alcohol in a small beaker. Add 90 mL distilled water. Add 0.1 M sodium carbonate drop by drop, swirling, until the solution turns blue-green. Top up to 100 mL. Label it and store it dark. (photo)
- [ ] **P1.6 Make 0.1 M sodium carbonate.** 1.06 g anhydrous sodium carbonate (or 2.86 g of the decahydrate washing-soda crystals) in water to 100 mL. Label it.
- [ ] **P1.7 Run the dilution series.** The script prints a randomized map: six concentrations of indicator (0 to 100 uM) in 1 mL of 10 mM sodium carbonate, three wells each, plus water blanks. Pipette to the map, place the plate, press Enter. `python -m wetstack g1-linearity`
- [ ] **P1.8 Stability run.** Leave the plate in place. The script reads every minute for 10 minutes and reports drift. `python -m wetstack g1-linearity --stability`

**Gate G1: First light** (`python -m wetstack gate G1`)

| Criterion | Target |
|---|---|
| Dilution series linearity (R-squared) | >= 0.98  |
| Repeat-read variation (CV) | <= 2 % |
| Drift over 10 minutes | <= 1 % |
| Water blank absorbance (plastic + meniscus) | <= 0.05  |

If it fails:

- Curve bends over at high concentration: the camera is saturating or the light pad is too bright. Dim the pad or shorten exposure.
- High CV: auto exposure is still on, or the plate moves. Re-lock and tape the frame.
- Drift: the light pad is warming up. Switch it on 15 minutes before reading.

Achievement: **First light**

### P2 First nonlinearity: manual XOR (Week 2)

**Goal.** Prove that indicator chemistry creates a nonlinearity a linear readout can use.

**Why.** This is the core claim of the whole project in its simplest form, done by hand before any electronics touch the liquid.

- **H2.** With two indicators of different pKa (bromothymol blue and phenol red), the absorbance features of a well separate XOR(acid, base) linearly. _Pass:_ Logistic regression on absorbance >= 95% accuracy (5-fold cross-validation, 48 wells); permutation p <= 0.01. _Control:_ The same classifier on the raw inputs reaches at most 75% (mathematical maximum for XOR). A bromothymol-blue-only plate also stays at or below 80%.

- [ ] **P2.1 Make the phenol red stock (0.2 mg/mL).** 20 mg phenol red in 5 mL isopropyl alcohol, add 90 mL water, a few drops of 0.1 M carbonate until red, top to 100 mL. If you bought a ready solution, note its concentration.
- [ ] **P2.2 Make the input stocks.** Acid A: 20 mM sodium bisulfate (0.24 g anhydrous NaHSO4 per 100 mL; check the pool product label says 93% or more). Base B: start at 20 mM sodium carbonate (0.212 g per 100 mL).
- [ ] **P2.3 Balance the inputs.** In one well: 1 mL medium (below) plus 50 uL A plus 50 uL B. If it is not the same green as a well with nothing added, adjust B's concentration and repeat. Record the final B concentration. Balanced inputs make 'both' look like 'neither', which is what makes the task XOR. (photo)
- [ ] **P2.4 Make the XOR medium.** Per 100 mL: 0.71 g sodium sulfate, 1 mL of 100 mM phosphate pH 7.6 (recipe in Materials), 6.25 mL bromothymol blue stock, 2.5 mL phenol red stock, water to 100 mL.
- [ ] **P2.5 Run the dual-indicator plates.** Two plates, 24 wells each, follow the randomized map. Each well gets 1 mL medium, then 50 uL A or water, then 50 uL B or water. Tap gently to mix, wait 2 minutes, read. `python -m wetstack g2-xor-manual --plates 2` (photo)
- [ ] **P2.6 Run the single-indicator control plate.** Same procedure with medium that has bromothymol blue only. This plate should fail. `python -m wetstack g2-xor-manual --plates 1 --control single-indicator`

**Gate G2: First XOR** (`python -m wetstack gate G2`)

| Criterion | Target |
|---|---|
| XOR accuracy, dual indicator | >= 0.95  |
| Raw-input linear baseline (must stay low) | <= 0.75  |
| Single-indicator control (must stay low) | <= 0.8  |
| Permutation test p-value | <= 0.01  |
| Wells in the dual-indicator set | >= 48  |

If it fails:

- Dual accuracy low because 'both' wells are not green: rebalance B (step P2.3).
- Single-indicator control passes: the classifier is using brightness, not absorbance. Check that you ran the current code.
- Accuracy low with clean colors: read too soon. Wait 5 minutes for CO2 bubbles to clear.

Achievement: **First XOR**

### P3 Electric write: the Faraday cell (Weeks 3-4)

**Goal.** Write chemistry with electrons, and prove that charge in maps to acid made.

**Why.** From here on, inputs are electrical. Faraday's law (96,485 coulombs per mole) is our calibration constant.

- **H3a.** Coulomb counting delivers the requested charge within 2%. _Pass:_ Mean absolute error <= 2% versus a multimeter in series. _Control:_ Zero-charge dose reads under 0.05 mC.
- **H3b.** Faradaic efficiency (acid made divided by charge/F) is at least 70% at the platinum anode in sulfate. _Pass:_ Efficiency >= 0.70, dose-response CV <= 5% over 3 repeats. _Control:_ Pipetted sodium bisulfate standards define the color-to-moles curve.

- [ ] **P3.1 Build the controller.** Breadboard first, following the pin map and wiring notes in the Architecture tab. Relay JD-VCC jumper removed. Fuse after the 9 V adapter. Photograph it before powering. (photo)
- [ ] **P3.2 Flash the firmware.** Arduino IDE 2.x: install the esp32 board package (Espressif), and libraries Adafruit ADS1X15, Adafruit AS7341, Adafruit INA219, OneWire, DallasTemperature. Open firmware/wetstack_ctl/wetstack_ctl.ino, select ESP32 Dev Module, upload. Then ping it. `python -m wetstack ping --port COM5`
- [ ] **P3.3 Dry test the relays.** No liquids. Run the relay test; you should hear each relay click in turn and see PASS for the interlock. `python -m wetstack relay-test`
- [ ] **P3.4 Print and fit the lid.** Print hardware/scad/plate_lid.scad in PETG with the wells you will use (default A3, A4, A5, A6, B3). Check every hole with the wire and tubing before going further. (photo)
- [ ] **P3.5 Make the electrodes.** Cut 5 platinum pieces of 18 mm. Crimp or tightly wrap each onto a copper lead, cover the joint with heat-shrink and a dab of epoxy so only platinum touches liquid. Push through the lid so 6 mm sits in the well. Counter electrode: a 2 mm graphite rod in the reservoir beaker. (photo)
- [ ] **P3.6 Verify the platinum.** Anodic test: one electrode in 50 mM sodium sulfate, 3 mA for 10 minutes. Real platinum stays bright and the liquid stays clear. Discoloration means the wire is fake; switch to graphite and tell me.
- [ ] **P3.7 Make salt bridges.** Heat 2 g agar in 100 mL of 0.25 M sodium sulfate (3.55 g) until clear. Draw into 2 mm silicone tubing with a syringe, no bubbles. Let set 20 minutes. Cut 70 mm lengths, bend into a U, one end in a well, one in the reservoir (100 mL beaker, 0.25 M sodium sulfate). (photo)
- [ ] **P3.8 Calibrate coulomb counting.** Multimeter in series on the mA range. Run doses of 5, 10, 20 and 40 mC into a well of plain sulfate; type the multimeter's steady current when asked. `python -m wetstack g3-faraday --charge-cal`
- [ ] **P3.9 Standards and dose response.** The script maps pipetted bisulfate standards (0-0.8 umol acid, 10 mM stock topped to 120 uL with water) and twelve 6 mC electrical doses in W1 (1 mL of 1 mM phosphate cell medium + 120 uL water), mixing 10 s after each dose. Efficiency is fitted only where the standards still change color. Three repeats; refill W1 between them. `python -m wetstack g3-faraday`

**Gate G3: First electric write** (`python -m wetstack gate G3`)

| Criterion | Target |
|---|---|
| Charge delivery error | <= 2 % |
| Faradaic efficiency | >= 0.7  |
| Dose-response repeatability (CV) | <= 5 % |

If it fails:

- Charge error high: the shunt is not 100 ohm. Measure it and set shunt_ohm in config/lab.json.
- Current far below 2 mA: a salt bridge has a bubble or dried out. Remake it.
- Low efficiency: dissolved oxygen is being reduced, or the platinum is fake. Run P3.6 again.
- Poor repeatability: mixing is incomplete. Increase mix time to 20 s or move the motor closer.

Achievement: **First electric write**

### P4 The chemical neuron: threshold and reset (Weeks 4-5)

**Goal.** Show that buffer sets a tunable firing threshold, and that reverse charge resets the well for 100+ cycles.

**Why.** A neuron is a weighted sum, a threshold and a reset. Charge is the weighted sum; buffer capacity is the threshold; reverse charge is the reset.

- **H4.** Response versus charge is sigmoidal, and its midpoint Q50 scales linearly with borax buffer concentration. _Pass:_ Q50 versus buffer R-squared >= 0.95 over 0.5, 1, 2 and 4 mM total borate; 10-90% width <= 40% of Q50. _Control:_ A well with no buffer fires at under 10% of the 1 mM Q50.
- **H5.** Writing acid then the same charge of base returns the well to baseline, with no fluid added, for 100 cycles. _Pass:_ Baseline absorbance shift <= 0.02 after reset; Q50 drift <= 10% from cycle 1 to 100. _Control:_ An unwritten neighbor well tracks background drift.

- [ ] **P4.1 Make neuron media.** Neuron medium (recipe in Materials) at 0, 0.5, 1, 2 and 4 mM total borate: 0, 0.5, 1, 2 and 4 mL of the 100 mM borate stock per 100 mL. The 0 mM control gets a trace of carbonate until blue-green.
- [ ] **P4.2 Threshold sweep.** One buffer level per electrode well, 1 mL each. The script doses in steps, mixes, reads, and fits a sigmoid per well. `python -m wetstack g4-threshold` (photo)
- [ ] **P4.3 Overnight reset run.** 1 mM borate well: 100 cycles of acid at 1.5 x Q50, read, equal base, read. Lid on to slow CO2 uptake. Check the bridge ends are submerged before you leave it. `python -m wetstack g4-reset --cycles 100`

**Gate G4: First chemical neuron** (`python -m wetstack gate G4`)

| Criterion | Target |
|---|---|
| Q50 vs buffer linearity | >= 0.95  |
| Threshold sharpness (width / Q50) | <= 0.4  |
| Baseline shift after reset | <= 0.02  |
| Q50 drift over the run | <= 10 % |
| Write/reset cycles completed | >= 100  |

If it fails:

- Thresholds not linear in borate: carbon dioxide from air is adding acid and buffer. Keep the lid on and use freshly made medium.
- Reset drifts acid-ward: the counter reservoir has drifted. Replace the reservoir solution (not the wells) and rerun.
- Indicator fades: bromothymol blue oxidizing at the anode. Lower current to 1.5 mA and report it.

Achievement: **First chemical neuron**

### P5 Logic and the first stack (Weeks 5-6)

**Goal.** Single chemical neurons compute AND and OR; a two-layer chemical network computes XOR.

**Why.** XOR is the classic task one threshold unit cannot do. Doing it with two layers of chemistry, relayed only linearly, is the MVP's headline proof.

- **H6a.** Buffer level alone turns one neuron into AND or OR. _Pass:_ Truth tables correct in 10 of 10 repeats each. _Control:_ Unbuffered well fires on any input (OR at best, never AND).
- **H6b.** OR neuron (excitatory) and AND neuron (inhibitory) feed an output neuron that computes XOR, with the relay purely linear. _Pass:_ XOR accuracy >= 95% over >= 40 randomized trials; relay code audited linear. _Control:_ Same network with the inhibitory link cut computes OR, not XOR.

- [ ] **P5.1 Find the AND and OR buffer levels.** From your G4 fits, the script proposes borate levels so one input dose crosses threshold (OR) or only two do (AND), and an output neuron level. Make those three media. `python -m wetstack g5-logic --plan`
- [ ] **P5.2 Truth tables.** Wells W1 = OR, W2 = AND. Each input row is dosed, mixed, read and reset, ten times. `python -m wetstack g5-logic --truth`
- [ ] **P5.3 Wire the stack.** W3 is the output neuron. Layer 2 dose = gain x layer-1 signal (acid for OR, base for AND). Gains are fixed after calibration and saved to config. `python -m wetstack g5-stack --calibrate`
- [ ] **P5.4 Run 40 randomized trials.** Expect about two hours. Photograph the plate at one trial of each input combination. `python -m wetstack g5-stack --trials 40` (photo)
- [ ] **P5.5 Cut-link control.** Same run with the AND-to-output gain set to zero. It should compute OR. `python -m wetstack g5-stack --trials 16 --cut-inhibition`

**Gate G5: First stack** (`python -m wetstack gate G5`)

| Criterion | Target |
|---|---|
| AND truth table accuracy | >= 1.0  |
| OR truth table accuracy | >= 1.0  |
| Stacked XOR accuracy | >= 0.95  |
| Randomized trials | >= 40  |
| Relay audited linear | == 1  |

If it fails:

- AND fires on one input: buffer too low; raise by 20%.
- XOR fails on input 1,1: inhibitory gain too small; it must be at least the excitatory gain.
- Errors cluster late in the run: reset ledger drift. Re-zero by running g4-reset --cycles 1 between blocks.

Achievement: **First stack**

### P6 Junctions: the ionic diode (Weeks 6-7)

**Goal.** Build a hydrogel junction that conducts ions better in one direction, from home-sourced polymers.

**Why.** Directional junctions are what let signals rise through stacked layers instead of echoing back.

- **H7.** A bipolar junction of cationic gel (agarose + chitosan) against anionic gel (agarose + alginate) rectifies ion current. _Pass:_ Median rectification ratio >= 2 at +/-2.5 V over 3 devices. _Control:_ Plain agarose tube: ratio <= 1.2.
- **H7b.** Under a slow sine drive the junction shows a pinched hysteresis loop (memory). _Pass:_ Visible pinched loop on the oscilloscope in X-Y mode at 0.1 Hz. _Control:_ 1 kohm resistor shows a straight line.

- [ ] **P6.1 Make Ag/AgCl electrodes.** In the labeled bleach jar only: 5 cm pieces of silver wire, 30 minutes in plain household bleach until dark purple-gray. Rinse well in distilled water. Never let bleach meet acid. (photo)
- [ ] **P6.2 Cationic gel.** Dissolve 1 g chitosan in 50 mL of 1% acetic acid (10 mL white vinegar + 40 mL water), stir until clear (hours; hotplate low). Mix 1:1 with hot 3% agarose in water to get 1.5% agarose / 1% chitosan.
- [ ] **P6.3 Anionic gel.** 1.5% agarose with 1% sodium alginate in water. Backup: swollen sodium polyacrylate paste.
- [ ] **P6.4 Cast three diode tubes and one control.** 40 mm of 3 mm silicone tube. Fill 20 mm with warm cationic gel by syringe, let set 10 minutes, then fill the rest with warm anionic gel pressed against it. Control: plain 1.5% agarose. Label the ends + (cationic) and - (anionic). (photo)
- [ ] **P6.5 I-V sweeps.** Each tube bridges two wells holding 10 mM table salt (58 mg non-iodized salt per 100 mL), one Ag/AgCl wire per well. Ag/AgCl needs chloride to work; silver reacts long before any chlorine could form at these voltages. 2 s dwell per step. `python -m wetstack g6-diode --devices 3 --control 1`
- [ ] **P6.6 Hysteresis on the scope.** Scope X on the cell voltage, Y across the 1 kohm sense resistor, X-Y mode. Run the sine drive and photograph the screen. `python -m wetstack g6-diode --sine 0.1` (photo)

**Gate G6: First diode** (`python -m wetstack gate G6`)

| Criterion | Target |
|---|---|
| Median rectification ratio | >= 2.0  |
| Plain-gel control ratio | <= 1.2  |
| Devices measured | >= 3  |

If it fails:

- Ratio near 1: the interface has an air gap. Recast pressing the second gel firmly against the first.
- Ratio drifts during the sweep: dwell too short; set 5 s.
- Still low: try the polyacrylate backup or the calcium exchange stretch step and tell me the numbers.

Achievement: **First diode**

### P7 Fiber eyes (Weeks 7-8)

**Goal.** Read a well through optical fiber into a spectral sensor as well as the camera does, including where the camera cannot see.

**Why.** Stacked layers bury chambers. Fiber is how we keep reading them.

- **H9.** LED-on minus LED-off fiber reads track camera absorbance across a dose sweep. _Pass:_ R-squared >= 0.95; with the plate covered, noise <= 3%. _Control:_ Fiber in an empty well reads constant.

- [ ] **P7.1 Print fiber parts.** The lid with a fiber boss over W1 (hardware/stl/plate_lid_fiber_A3.stl; from hardware/scad/plate_lid.scad with fiber_wells = [[0,2]]), plus the LED coupler and the sensor cap (hardware/stl/fiber_led_coupler.stl and fiber_sensor_cap.stl; hardware/scad/fiber_parts.scad, part = "led" or "cap"). Opaque (black) PETG or resin so room light can't leak into the fiber; resin parts fully cured and washed. (photo)
- [ ] **P7.2 Cut and polish fiber.** Cut 1 mm PMMA fiber with a fresh hot blade, polish each end on 2000-grit wet paper in figure-eights for 30 seconds.
- [ ] **P7.3 Assemble and read.** Light pad below, fiber tip 2 mm above the liquid, far end in the sensor cap on the AS7341. `python -m wetstack spec --diff`
- [ ] **P7.4 Dose sweep with both readers.** Camera and fiber read the same well through a dose sweep, then again with a dark cover over the plate (camera blinded). `python -m wetstack g7-fiber`

**Gate G7: Fiber eyes** (`python -m wetstack gate G7`)

| Criterion | Target |
|---|---|
| Fiber vs camera agreement | >= 0.95  |
| Fiber noise with camera blinded | <= 3 % |

If it fails:

- Weak signal: polish the fiber ends again, and raise AS7341 gain.
- Noisy: room light leaking; use the differential mode and the sensor cap.

Achievement: **Fiber eyes**

### P8 Sun power and energy per operation (Weeks 8-9)

**Goal.** Run the controller and dosing from sunlight and measure joules per chemical operation.

**Why.** Low power and minimal consumables were the goal from the start. This is where we put numbers on it.

- **H10.** A 6 V panel with a single 18650 buffer runs a 4-hour daylight session of 100+ writes without a brownout. _Pass:_ >= 4 h, >= 100 writes, 0 brownouts; joules per write recorded. _Control:_ Same session on the wall adapter gives the same dose accuracy.

- [ ] **P8.1 Build the power board.** Panel to CN3791 charger to protected 18650. Battery to INA219 to two MT3608 boosts: set one to 5.0 V (ESP32 5V pin) and one to 9.0 V (electrolysis supply) with the multimeter before connecting anything. (photo)
- [ ] **P8.2 Daylight session.** Panel in a window or outside in shade-free light. The script cycles the 1 mM neuron and logs power. Block the laptop's USB 5 V line (a USB power-blocker adapter, or Kapton tape over the VBUS pin of the USB-A plug) so the battery is the controller's only supply; otherwise USB powers the ESP32 and a brownout can never show up. `python -m wetstack g8-solar --hours 4`

**Gate G8: Sun-powered** (`python -m wetstack gate G8`)

| Criterion | Target |
|---|---|
| Session length | >= 4 h |
| Writes completed | >= 100  |
| Brownouts | == 0  |
| Energy per write | record J |

If it fails:

- Brownout at relay switching: add 470 uF across the 5 V rail.
- Energy per write dominated by relay coils (about 75 mW each while held): switch to latching relays or MOSFET routing for WetStack-1. The twin predicts this.
- Battery drains: panel too small for continuous dosing; lengthen idle time between writes.

Achievement: **Sun-powered**

### P9 MVP integration (Week 10)

**Goal.** Run the whole system in one demonstration and publish the report.

**Why.** Each gate proved a part. The MVP proves the parts work together.

- [ ] **P9.1 Full demo run.** Solar powered; stacked XOR with camera and fiber readout; the diode tube installed as W3's bridge; 20 trials. The demo reads its output through the fiber at W3 (A5, the OUT neuron), so first print a lid with fiber_wells = [[0,4]] in hardware/scad/plate_lid.scad; the P7 lid puts the fiber over W1. `python -m wetstack mvp-demo --trials 20` (photo)
- [ ] **P9.2 Generate the report.** Collects every proof file into docs/MVP_REPORT.md. Commit, then git tag v1.0-mvp. `python -m wetstack report`
- [ ] **P9.3 Debrief.** Upload the report and three photos to the workspace and ask for the lab-manager review. We plan WetStack-1 from what broke.

**Gate G9: MVP complete** (`python -m wetstack gate G9`)

| Criterion | Target |
|---|---|
| Gates G0-G8 passed | >= 9  |
| Integrated demo XOR accuracy | >= 0.9  |

If it fails:

- Integrated accuracy below the stack result: compare per-trial logs for the readout path that differs.

Achievement: **WetStack-0 MVP**

## Stretch goals

- **Photochromic short-term memory.** UV write (365 nm via fiber), visible erase, decay time measured. Craft photochromic pigment in clear epoxy. A memory that fades on its own, like short-term memory.
- **Delay neuron (iodine clock).** Vitamin C, iodine tincture, 3% peroxide, starch. Fires abruptly after a delay set by input dose: a timing element.
- **Calcium-exchanged diode.** Soak the anionic side in calcium chloride. Multivalent counter-ions raised a published hydrogel diode's ratio from 3 to over 70.
- **Diode-coupled wells.** Replace a salt bridge with a diode tube and show writes pass one way more easily than the other.
- **Resin micro-chambers.** 96 chambers at 50 uL in clear resin; measure how dose time shrinks with volume.

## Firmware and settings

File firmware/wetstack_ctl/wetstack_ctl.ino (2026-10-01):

// WetStack-0 controller firmware
// Board: classic ESP32 (ESP32-WROOM-32 DevKit V1). Arduino-ESP32 core 2.x or 3.x.
// Libraries (Library Manager): Adafruit ADS1X15, Adafruit AS7341, Adafruit INA219,
//                               OneWire, DallasTemperature.
// Protocol: one text command per line at 115200 baud; one JSON object per reply line.
// Long commands (IV, SINE) stream rows and end with {"done":true}.

#include <Wire.h>
#include <Preferences.h>
#include <Adafruit_ADS1X15.h>
#include <Adafruit_AS7341.h>
#include <Adafruit_INA219.h>
#include <OneWire.h>
#include <DallasTemperature.h>
#include "esp_system.h"

// ---------------------------------------------------------------- pins
const int PIN_SDA = 21, PIN_SCL = 22;
const int PIN_DAC1 = 25, PIN_DAC2 = 26;
const int PIN_RELAY_EN = 16;           // CH1 master enable
const int PIN_RELAY_POL = 17;          // CH2 + CH3 (both IN pins) polarity pair
const int PIN_WELL[5] = {18, 19, 23, 32, 33};   // CH4..CH8
const int PIN_MIX = 13;                // MOSFET module: vibration motor
const int PIN_LED = 14;                // MOSFET module: fiber LED
const int PIN_ONEWIRE = 4;
const int PIN_STATUS = 2;

const bool RELAY_ACTIVE_LOW = true;    // most opto relay boards switch on a LOW input
const float OVERCURRENT_MA = 15.0;
const float NO_CURRENT_MA = 0.05;
const float MAX_DOSE_MC = 2000.0;
const char *FW = "wetstack-1.0";

Adafruit_ADS1115 ads1;                 // 0x48: electrolysis shunt (A0-A1)
Adafruit_ADS1115 ads2;                 // 0x49: diode sense (A0-A1) and cell (A2-A3)
Adafruit_AS7341 as7341;
Adafruit_INA219 ina219;
OneWire oneWire(PIN_ONEWIRE);
DallasTemperature temps(&oneWire);
Preferences prefs;

bool hasAds1 = false, hasAds2 = false, hasSpec = false, hasIna = false, hasTemp = false;
float shuntOhm = 100.0;
float senseOhm = 1000.0;
uint32_t boots = 0;
int activeWell = 0;                    // 0 = none; firmware interlock guarantees at most one

// ---------------------------------------------------------------- relays
void relayWrite(int pin, bool on) {
  digitalWrite(pin, (on ^ RELAY_ACTIVE_LOW) ? HIGH : LOW);
}

void relayInit(int pin) {
  digitalWrite(pin, RELAY_ACTIVE_LOW ? HIGH : LOW);   // off before becoming an output
  pinMode(pin, OUTPUT);
  relayWrite(pin, false);
}

void allOff() {
  relayWrite(PIN_RELAY_EN, false);
  delay(30);
  for (int i = 0; i < 5; i++) relayWrite(PIN_WELL[i], false);
  relayWrite(PIN_RELAY_POL, false);
  activeWell = 0;
  analogWrite(PIN_MIX, 0);
  digitalWrite(PIN_LED, LOW);
  dacWrite(PIN_DAC1, 0);
  dacWrite(PIN_DAC2, 0);
  digitalWrite(PIN_STATUS, LOW);
}

// Interlock: every well relay is switched off before one is switched on.
void selectWell(int w) {
  for (int i = 0; i < 5; i++) relayWrite(PIN_WELL[i], false);
  delay(30);
  if (w >= 1 && w <= 5) {
    relayWrite(PIN_WELL[w - 1], true);
    activeWell = w;
  } else {
    activeWell = 0;
  }
}

int countActiveWells() {
  int n = 0;
  for (int i = 0; i < 5; i++) {
    bool level = digitalRead(PIN_WELL[i]);
    bool on = RELAY_ACTIVE_LOW ? (level == LOW) : (level == HIGH);
    if (on) n++;
  }
  return n;
}

// ---------------------------------------------------------------- helpers
float shuntmA() {
  int16_t raw = ads1.readADC_Differential_0_1();
  return ads1.computeVolts(raw) / shuntOhm * 1000.0;
}

void setDiff(float v) {
  if (v > 3.2) v = 3.2;
  if (v < -3.2) v = -3.2;
  int code = (int)(fabs(v) / 3.3 * 255.0 + 0.5);
  if (code > 255) code = 255;
  if (v >= 0) { dacWrite(PIN_DAC1, code); dacWrite(PIN_DAC2, 0); }
  else        { dacWrite(PIN_DAC1, 0);    dacWrite(PIN_DAC2, code); }
}

void readDiode(float &vCell, float &iuA) {
  float vs = 0, vc = 0;
  const int n = 8;
  for (int k = 0; k < n; k++) {
    ads2.setGain(GAIN_EIGHT);          // +/-0.512 V across the 1 kohm sense resistor
    vs += ads2.computeVolts(ads2.readADC_Differential_0_1());
    ads2.setGain(GAIN_ONE);            // +/-4.096 V across the cell
    vc += ads2.computeVolts(ads2.readADC_Differential_2_3());
  }
  vs /= n; vc /= n;
  iuA = vs / senseOhm * 1e6;
  vCell = vc;
}

void err(const char *msg) {
  Serial.printf("{\"ok\":false,\"err\":\"%s\"}\n", msg);
}

// ---------------------------------------------------------------- commands
void cmdPing() {
  esp_reset_reason_t rr = esp_reset_reason();
  Serial.printf("{\"ok\":true,\"fw\":\"%s\",\"ads1\":%s,\"ads2\":%s,\"as7341\":%s,\"ina219\":%s,"
                "\"ds18b20\":%s,\"boots\":%lu,\"reset_reason\":%d,\"brownout_reset\":%s,\"uptime_ms\":%lu,"
                "\"shunt_ohm\":%.3f}\n",
                FW, hasAds1 ? "true" : "false", hasAds2 ? "true" : "false", hasSpec ? "true" : "false",
                hasIna ? "true" : "false", hasTemp ? "true" : "false", (unsigned long)boots, (int)rr,
                rr == ESP_RST_BROWNOUT ? "true" : "false", (unsigned long)millis(), shuntOhm);
}

void cmdRelayTest() {
  allOff();
  int pins[7] = {PIN_RELAY_EN, PIN_RELAY_POL, PIN_WELL[0], PIN_WELL[1], PIN_WELL[2], PIN_WELL[3], PIN_WELL[4]};
  for (int i = 0; i < 7; i++) {
    relayWrite(pins[i], true);
    delay(300);
    relayWrite(pins[i], false);
    delay(150);
  }
  bool pass = true;
  for (int w = 1; w <= 5; w++) {
    selectWell(w);
    selectWell((w % 5) + 1);
    if (countActiveWells() != 1) pass = false;
  }
  allOff();
  Serial.printf("{\"ok\":true,\"channels\":8,\"interlock\":\"%s\"}\n", pass ? "PASS" : "FAIL");
}

void cmdDose(int well, const char *mode, float targetmC, float maxS) {
  if (!hasAds1) { err("ADS1115 #1 (0x48) not found"); return; }
  if (well < 1 || well > 5) { err("well must be 1-5"); return; }
  bool acid = strcmp(mode, "ACID") == 0;
  bool base = strcmp(mode, "BASE") == 0;
  if (!acid && !base) { err("mode must be ACID or BASE"); return; }
  if (targetmC <= 0 || targetmC > MAX_DOSE_MC) { err("charge out of range"); return; }
  if (maxS <= 0 || maxS > 1800) maxS = 300;

  allOff();
  digitalWrite(PIN_STATUS, HIGH);
  relayWrite(PIN_RELAY_POL, base);     // off = ACID (well electrode is the anode)
  delay(30);
  selectWell(well);
  delay(30);
  relayWrite(PIN_RELAY_EN, true);

  uint32_t t0 = micros(), tLast = t0, tIna = t0;
  float qmC = 0, peak = 0, sumI = 0, lastI = 0, energymJ = 0;
  uint32_t samples = 0, overSince = 0;
  bool over = false, timeout = false, noCurrent = false, saturated = false;
  while (true) {
    float i = shuntmA();
    uint32_t t = micros();
    float dt = (t - tLast) / 1e6;
    tLast = t;
    qmC += 0.5 * (i + lastI) * dt;     // mA * s = mC
    lastI = i;
    sumI += i; samples++;
    if (i > peak) peak = i;
    if (i > 20.0) saturated = true;
    if (hasIna && (t - tIna) > 20000) {
      energymJ += ina219.getPower_mW() * ((t - tIna) / 1e6);
      tIna = t;
    }
    if (i > OVERCURRENT_MA) {
      if (overSince == 0) overSince = t;
      if (t - overSince > 200000) { over = true; break; }
    } else {
      overSince = 0;
    }
    float elapsed = (t - t0) / 1e6;
    if (elapsed > 3.0 && (sumI / samples) < NO_CURRENT_MA) { noCurrent = true; break; }
    if (qmC >= targetmC) break;
    if (elapsed > maxS) { timeout = true; break; }
  }
  relayWrite(PIN_RELAY_EN, false);
  delay(30);
  selectWell(0);
  relayWrite(PIN_RELAY_POL, false);
  digitalWrite(PIN_STATUS, LOW);
  float dur = (tLast - t0) / 1e6;
  bool ok = !over && !noCurrent;
  char energy[24];
  if (hasIna) snprintf(energy, sizeof(energy), "%.2f", energymJ);
  else snprintf(energy, sizeof(energy), "null");
  Serial.printf("{\"ok\":%s,\"well\":%d,\"mode\":\"%s\",\"target_mC\":%.4f,\"delivered_mC\":%.4f,"
                "\"duration_s\":%.3f,\"mean_mA\":%.4f,\"peak_mA\":%.4f,\"overrange\":%s,\"overcurrent\":%s,"
                "\"timeout\":%s,\"no_current\":%s,\"energy_mJ\":%s%s}\n",
                ok ? "true" : "false", well, acid ? "ACID" : "BASE", targetmC, qmC, dur,
                samples ? sumI / samples : 0.0, peak, saturated ? "true" : "false",
                over ? "true" : "false", timeout ? "true" : "false", noCurrent ? "true" : "false",
                energy,
                noCurrent ? ",\"err\":\"no current: check salt bridge and electrode\"" :
                over ? ",\"err\":\"overcurrent: check for a short\"" : "");
}

void cmdMix(float seconds, int duty) {
  if (seconds < 0 || seconds > 120) { err("mix seconds 0-120"); return; }
  if (duty < 0) duty = 0;
  if (duty > 100) duty = 100;
  analogWrite(PIN_MIX, duty * 255 / 100);
  delay((uint32_t)(seconds * 1000));
  analogWrite(PIN_MIX, 0);
  Serial.printf("{\"ok\":true,\"mixed_s\":%.1f}\n", seconds);
}

bool readSpec(uint16_t out[10]) {
  uint16_t r[12];
  if (!as7341.readAllChannels(r)) return false;
  // F1-F4 = r[0..3], F5-F8 = r[6..9], clear = r[10], NIR = r[11]
  out[0] = r[0]; out[1] = r[1]; out[2] = r[2]; out[3] = r[3];
  out[4] = r[6]; out[5] = r[7]; out[6] = r[8]; out[7] = r[9];
  out[8] = r[10]; out[9] = r[11];
  return true;
}

void printArr(const char *name, uint16_t *a, int n, bool comma) {
  Serial.printf("\"%s\":[", name);
  for (int i = 0; i < n; i++) Serial.printf("%u%s", a[i], i < n - 1 ? "," : "");
  Serial.printf("]%s", comma ? "," : "");
}

void cmdSpec(bool diff, bool boardLed) {
  if (!hasSpec) { err("AS7341 not found"); return; }
  uint16_t on[10], off[10], d[10];
  if (boardLed) { as7341.setLEDCurrent(10); as7341.enableLED(true); }
  else digitalWrite(PIN_LED, HIGH);
  delay(50);
  bool okOn = readSpec(on);
  if (boardLed) as7341.enableLED(false); else digitalWrite(PIN_LED, LOW);
  delay(50);
  bool okOff = readSpec(off);
  if (!okOn || !okOff) { err("AS7341 read failed"); return; }
  for (int i = 0; i < 10; i++) {
    int32_t v = (int32_t)on[i] - (int32_t)off[i];
    d[i] = v < 0 ? 0 : (uint16_t)v;
  }
  Serial.print("{\"ok\":true,\"bands_nm\":[415,445,480,515,555,590,630,680],");
  uint16_t onB[8], offB[8], dB[8];
  for (int i = 0; i < 8; i++) { onB[i] = on[i]; offB[i] = off[i]; dB[i] = diff ? d[i] : on[i]; }
  printArr("on", onB, 8, true);
  printArr("off", offB, 8, true);
  printArr("diff", dB, 8, true);
  Serial.printf("\"clear_on\":%u,\"nir_on\":%u}\n", on[8], on[9]);
}

void cmdTemp() {
  if (!hasTemp) { err("DS18B20 not found"); return; }
  temps.requestTemperatures();
  float c = temps.getTempCByIndex(0);
  if (c == DEVICE_DISCONNECTED_C) { err("DS18B20 disconnected"); return; }
  Serial.printf("{\"ok\":true,\"temp_C\":%.3f}\n", c);
}

void cmdPower() {
  if (!hasIna) { err("INA219 not found"); return; }
  Serial.printf("{\"ok\":true,\"bus_V\":%.3f,\"current_mA\":%.2f,\"power_mW\":%.1f}\n",
                ina219.getBusVoltage_V(), ina219.getCurrent_mA(), ina219.getPower_mW());
}

void cmdIV(float vmin, float vmax, float step, int dwellMs) {
  if (!hasAds2) { err("ADS1115 #2 (0x49) not found"); return; }
  if (step == 0 || (vmax - vmin) / step < 0) { err("step sign does not reach vmax"); return; }
  int n = (int)lroundf((vmax - vmin) / step) + 1;
  if (n > 400) { err("too many points"); return; }
  if (dwellMs < 50) dwellMs = 50;
  for (int k = 0; k < n; k++) {
    float v = vmin + k * step;
    setDiff(v);
    delay(dwellMs);
    float vc, i;
    readDiode(vc, i);
    Serial.printf("{\"v_set\":%.4f,\"v_cell\":%.5f,\"i_uA\":%.4f}\n", v, vc, i);
  }
  setDiff(0);
  Serial.println("{\"done\":true}");
}

void cmdSine(float freq, float amp, int cycles) {
  if (!hasAds2) { err("ADS1115 #2 (0x49) not found"); return; }
  if (freq <= 0 || freq > 5 || amp <= 0 || amp > 3.2 || cycles < 1 || cycles > 20) { err("sine args"); return; }
  const uint32_t stepMs = 50;
  uint32_t steps = (uint32_t)(cycles / freq * 1000.0 / stepMs);
  uint32_t t0 = millis();
  for (uint32_t k = 0; k < steps; k++) {
    float t = (millis() - t0) / 1000.0;
    float v = amp * sinf(2 * PI * freq * t);
    setDiff(v);
    float vc, i;
    readDiode(vc, i);
    Serial.printf("{\"t_s\":%.3f,\"v_set\":%.4f,\"v_cell\":%.5f,\"i_uA\":%.4f}\n", t, v, vc, i);
    while (millis() - t0 < (k + 1) * stepMs) delay(1);
  }
  setDiff(0);
  Serial.println("{\"done\":true}");
}

void cmdHelp() {
  Serial.println("{\"ok\":true,\"commands\":\"PING|RELAYTEST|DOSE w ACID|BASE mC [max_s]|MIX s [duty]|"
                 "SPEC [DIFF|ON] [EXT|BOARD]|TEMP|POWER|IV vmin vmax step dwell_ms|SINE f amp cycles|"
                 "SET SHUNT ohm|SET SENSE ohm|SAFE|HELP\"}");
}

// ---------------------------------------------------------------- main
char line[160];
size_t lineLen = 0;

void handle(char *buf) {
  char *argv[8];
  int argc = 0;
  for (char *tok = strtok(buf, " \t\r"); tok && argc < 8; tok = strtok(nullptr, " \t\r")) argv[argc++] = tok;
  if (argc == 0) return;
  for (char *p = argv[0]; *p; p++) *p = toupper(*p);
  String c = argv[0];
  if (c == "PING") cmdPing();
  else if (c == "RELAYTEST") cmdRelayTest();
  else if (c == "DOSE" && argc >= 4) {
    for (char *p = argv[2]; *p; p++) *p = toupper(*p);
    cmdDose(atoi(argv[1]), argv[2], atof(argv[3]), argc >= 5 ? atof(argv[4]) : 300);
  }
  else if (c == "MIX" && argc >= 2) cmdMix(atof(argv[1]), argc >= 3 ? atoi(argv[2]) : 100);
  else if (c == "SPEC") {
    bool diff = true, board = false;
    for (int i = 1; i < argc; i++) {
      for (char *p = argv[i]; *p; p++) *p = toupper(*p);
      if (strcmp(argv[i], "ON") == 0) diff = false;
      if (strcmp(argv[i], "BOARD") == 0) board = true;
    }
    cmdSpec(diff, board);
  }
  else if (c == "TEMP") cmdTemp();
  else if (c == "POWER") cmdPower();
  else if (c == "IV" && argc >= 5) cmdIV(atof(argv[1]), atof(argv[2]), atof(argv[3]), atoi(argv[4]));
  else if (c == "SINE" && argc >= 4) cmdSine(atof(argv[1]), atof(argv[2]), atoi(argv[3]));
  else if (c == "SET" && argc >= 3) {
    for (char *p = argv[1]; *p; p++) *p = toupper(*p);
    float v = atof(argv[2]);
    if (v <= 0) { err("value must be positive"); return; }
    if (strcmp(argv[1], "SHUNT") == 0) { shuntOhm = v; prefs.putFloat("shunt", v); }
    else if (strcmp(argv[1], "SENSE") == 0) { senseOhm = v; prefs.putFloat("sense", v); }
    else { err("SET SHUNT|SENSE"); return; }
    Serial.printf("{\"ok\":true,\"shunt_ohm\":%.3f,\"sense_ohm\":%.3f}\n", shuntOhm, senseOhm);
  }
  else if (c == "SAFE") { allOff(); Serial.println("{\"ok\":true}"); }
  else if (c == "HELP") cmdHelp();
  else err("unknown command or missing arguments; send HELP");
}

void setup() {
  relayInit(PIN_RELAY_EN);
  relayInit(PIN_RELAY_POL);
  for (int i = 0; i < 5; i++) relayInit(PIN_WELL[i]);
  pinMode(PIN_MIX, OUTPUT);
  pinMode(PIN_LED, OUTPUT);
  pinMode(PIN_STATUS, OUTPUT);
  Serial.begin(115200);
  Wire.begin(PIN_SDA, PIN_SCL);
  allOff();

  prefs.begin("wetstack", false);
  boots = prefs.getUInt("boots", 0) + 1;
  prefs.putUInt("boots", boots);
  shuntOhm = prefs.getFloat("shunt", 100.0);
  senseOhm = prefs.getFloat("sense", 1000.0);

  hasAds1 = ads1.begin(0x48);
  if (hasAds1) { ads1.setGain(GAIN_TWO); ads1.setDataRate(RATE_ADS1115_860SPS); }
  hasAds2 = ads2.begin(0x49);
  if (hasAds2) { ads2.setGain(GAIN_TWO); ads2.setDataRate(RATE_ADS1115_475SPS); }
  hasSpec = as7341.begin();
  if (hasSpec) { as7341.setATIME(100); as7341.setASTEP(999); as7341.setGain(AS7341_GAIN_256X); }
  hasIna = ina219.begin();
  temps.begin();
  hasTemp = temps.getDeviceCount() > 0;
  cmdPing();
}

void loop() {
  while (Serial.available()) {
    char ch = (char)Serial.read();
    if (ch == '\n') {
      line[lineLen] = 0;
      handle(line);
      lineLen = 0;
    } else if (lineLen < sizeof(line) - 1) {
      line[lineLen++] = ch;
    }
  }
}

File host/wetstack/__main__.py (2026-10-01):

"""python -m wetstack <command> [--sim] ...   (run from the repo root)"""
from __future__ import annotations

import argparse
import json
import sys

from . import experiments as ex
from .core import evaluate, load_config, print_gate, proof_path


def build_parser() -> argparse.ArgumentParser:
    ap = argparse.ArgumentParser(prog="wetstack", description="WetStack-0 lab commands")
    ap.add_argument("--sim", action="store_true", help="run against the digital twin")
    ap.add_argument("--port", default=None, help="serial port (default from config/lab.json)")
    # Bench commands also accept --sim and --port after the command name, as the manual writes them
    # (python -m wetstack g1-linearity --sim). SUPPRESS keeps an omitted option from overwriting
    # one given before the command.
    bench = argparse.ArgumentParser(add_help=False)
    bench.add_argument("--sim", action="store_true", default=argparse.SUPPRESS, help="run against the digital twin")
    bench.add_argument("--port", default=argparse.SUPPRESS, help="serial port (default from config/lab.json)")
    sub = ap.add_subparsers(dest="cmd", required=True)

    def cmd(name: str, **kw) -> argparse.ArgumentParser:
        return sub.add_parser(name, parents=[bench], **kw)

    st = cmd("selftest", help="run every gate against the digital twin")
    st.add_argument("--verbose", action="store_true")
    cmd("ping", help="talk to the controller")
    cmd("relay-test", help="click through relays and check the interlock")
    sp = cmd("spec", help="one AS7341 read")
    sp.add_argument("--diff", action="store_true")
    cam = cmd("camera", help="lock exposure and preview")
    cam.add_argument("--lock", action="store_true")
    cam.add_argument("--preview", action="store_true")
    cmd("calibrate-rois", help="click well centers")
    g = cmd("gate", help="show a gate's status")
    g.add_argument("gate")
    cmd("sign-safety", help="record the safety sign-off")

    p0 = cmd("g0-pipette")
    p0.add_argument("--volume", type=int, choices=[100, 1000], required=True)
    p1 = cmd("g1-linearity")
    p1.add_argument("--stability", action="store_true")
    p2 = cmd("g2-xor-manual")
    p2.add_argument("--plates", type=int, default=2)
    p2.add_argument("--control", choices=["single-indicator"], default=None)
    p3 = cmd("g3-faraday")
    p3.add_argument("--charge-cal", action="store_true")
    cmd("g4-threshold")
    p4 = cmd("g4-reset")
    p4.add_argument("--cycles", type=int, default=100)
    p5 = cmd("g5-logic")
    p5.add_argument("--plan", action="store_true")
    p5.add_argument("--truth", action="store_true")
    p6 = cmd("g5-stack")
    p6.add_argument("--calibrate", action="store_true")
    p6.add_argument("--trials", type=int, default=0)
    p6.add_argument("--cut-inhibition", action="store_true")
    p7 = cmd("g6-diode")
    p7.add_argument("--devices", type=int, default=3)
    p7.add_argument("--control", type=int, default=1)
    p7.add_argument("--sine", type=float, default=None)
    cmd("g7-fiber")
    p8 = cmd("g8-solar")
    p8.add_argument("--hours", type=float, default=4.0)
    p9 = cmd("mvp-demo")
    p9.add_argument("--trials", type=int, default=20)
    cmd("report")
    sv = sub.add_parser("serve", help="open the lab workspace, saving into the repo")
    sv.add_argument("--port", type=int, default=8765)
    sv.add_argument("--open", action="store_true", help="open it in your browser")
    qs = sub.add_parser("questions", help="list open lab questions (for Claude Code)")
    qs.add_argument("--all", action="store_true", help="include answered ones")
    an = sub.add_parser("answer", help="answer a lab question by id")
    an.add_argument("id")
    an.add_argument("--text", default=None)
    an.add_argument("--file", default=None, help="read the answer from a text file")
    pg = sub.add_parser("progress", help="progress file tools")
    pg.add_argument("action", choices=["status", "import", "export", "restore"])
    pg.add_argument("path", nargs="?", default=None)
    return ap


def main(argv: list[str] | None = None) -> int:
    a = build_parser().parse_args(argv)
    sim, port = a.sim, a.port
    proof = None
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

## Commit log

2026-10-01 WetStack-0 initial build: plan, digital twin, experiments, firmware, CAD, BOM, workspace
    [BOM_electronics.csv, BOM_equipment.csv, BOM_materials.csv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]
2026-10-01 Review fixes: CLI flag placement, sim raw data, g5-stack, g8 fill, docs
    Bugs found reviewing the imported WetStack-0 code:
    - CLI: --sim and --port were only accepted before the command, but the
    manual, README and workspace all write them after it
    ("selftest --sim" in P0.3, "ping --port COM5", "g1-linearity --sim"),
    and argparse rejected every one. Bench commands now accept them on
    either side (SUPPRESS defaults so an omitted flag doesn't override).
    - Twin runs wrote data/raw/<stamp>-<tag>/ with no -sim suffix, so the
    data/raw/*-sim/ ignore rule never matched and the workspace Commit
    button (git add data/raw) committed twin output as bench data.
    session_dir() now takes the sim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
    [__main__.py, camera.py, content.py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]
2026-10-01 Add one-click Windows launcher: venv setup, dependency check, start
    start_wetstack.bat, double-clicked from the repo folder:
    - finds Python 3.10+ through the PEP 514 registry keys first (3.12
    preferred, then 3.13, 3.11, 3.14, 3.10), then py -3 and python;
    probes read stdin from nul so the new install manager can't block on
    a hidden auto-install prompt
    - creates .venv, or rebuilds it if its Python is gone or too old
    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
2026-10-01 Launcher picks a free port instead of stopping when 8765 is taken
    On Windows the launcher stopped with "Port 8765 is in use by another
    program" right after creating .venv. The old check connected to the
    port with a 2 s timeout, and Windows takes about 2 s to refuse a
    connection to a closed localhost port, so a free port could read as
    busy.
    - tools/check_env.py --pick-port START replaces --running. It tests
    each port from START to START+19 by binding to it (instant), and only
    pings ports that are taken, to recognise this folder's server. It
    prints one line for the launcher: RUNNING <port> (open it), FREE
    <port> (serve there) or NONE; notes on skipped ports go to stderr.
    - start_wetst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
    [check_env.py, server.py]
